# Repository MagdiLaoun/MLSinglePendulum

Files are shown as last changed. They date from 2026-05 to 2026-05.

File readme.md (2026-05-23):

# Readme
This repository contains all the files needed to build a simple pendulum.
- **Inverted pendulum (English).pdf**: theory of pendulum kinematics and balance control, English version
- **Inverted pendulum (French).pdf**: theory of pendulum kinematics and balance control, French version
- **ComponentList.md**: Bill of material of the machine
- **Single Pendulum STL**: Folder containing all the 3D-print parts in stl format
- **Single Pendulum Circuit**: Folder containing the pcb (schematic + footprint) drawn on Kicad, this circuit allows to connect electrically all the parts together (motor, controller, etc.)
- **Single Pendulum C++**: Folder containing the source code of the controller, written in C++, in VSCode PlatformIO
- **Single Pendulum SwiftUI**: Folder containing the source code of the program on the computer to set-up the system, to set the parameters and to launch the machine, written in SwiftUI, for MacOS computer

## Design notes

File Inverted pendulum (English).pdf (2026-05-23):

# Inverted pendulum

Magdi Laoun, 17.12.2025

## 1 Abstract

An inverted pendulum is a pendulum that is held in equilibrium at the top in an unstable position. It can pivot at its base around an axis that is attached to a carriage capable of moving horizontally. With the help of a motor, the carriage moves to try to maintain this equilibrium position.

An angular sensor mounted on the carriage axis measures the pendulum’s angle relative to the vertical in real time, and this data is processed by a microcontroller, which controls the motor to maintain balance.

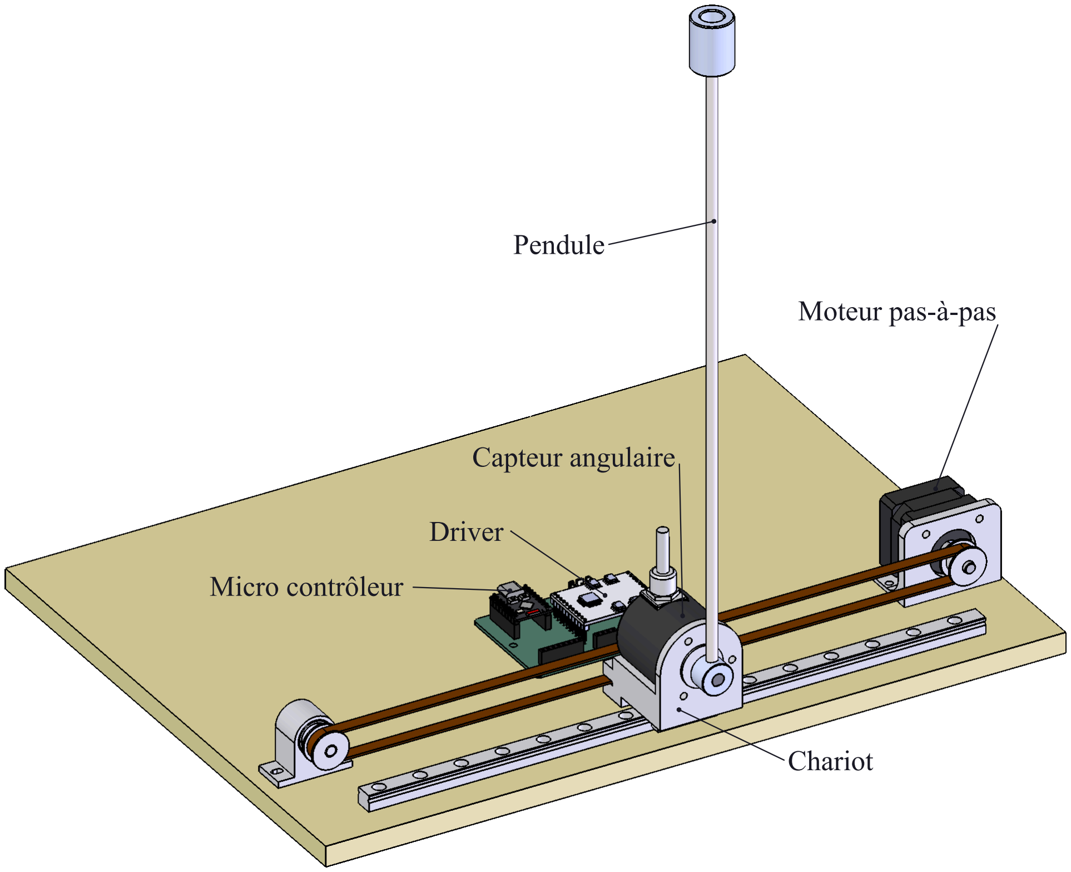
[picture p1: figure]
Pendule; Moteur pas-à-pas; Capteur angulaire; Chariot; Micro contrôleur; Driver
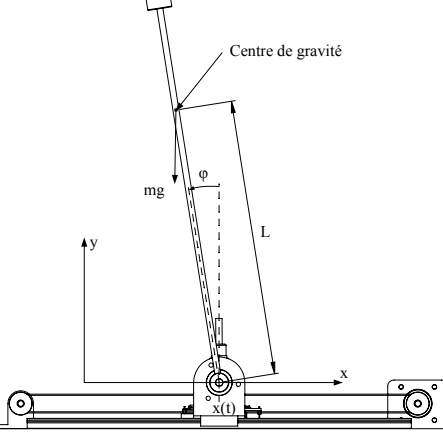
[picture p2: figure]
Centre de gravité

Figure 1: Geometry of the pendulum

## 2 Objectives

- Determine the movement of the carriage (and thus the motor) based on the pendulum’s angle and position, so as to keep it vertical and centered on the rail.
- Determine the motor control coefficients needed to keep this pendulum in balance.

## 3 Data and hypotheses

- The motor has 200 steps per revolution and 16 microsteps per step, which amounts to 3,200 microsteps per revolution. The motor is a stepper motor. Consequently, the motor’s position, speed, and acceleration do not depend on the load but solely on the electrical command provided by the controller.
- The motor pulley has a circumference of 40 mm. From this, we can deduce that the carriage moves 10 mm in 800 steps per revolution.
- The angle sensor mounted on the carriage, which measures the angular position of the pendulum, has a resolution of 10,000 counts per revolution.
- The total mass, moment of inertia, and center of gravity of the pendulum are known and provided by 3D modeling software.
- The pendulum’s axis, at its base, is fixed by the carriage, with no play and no friction.
- The carriage moves only horizontally along the x-axis.
- All units used in the formulas and calculations are those of the International System of Units. For practical and readability reasons, different units may be used to denote a given value or result, such as millimeters for length, or grams
- 1 -

## 4 Settings and terminology

Paramètre | Signification
m | segment mass i
l | segment length i
p | Angular position of the pendulum
φ̇ | Angular velocity of the pendulum
φ̈ | Angular acceleration of the pendulum
x | Carriage position
ẋ | Carriage velocity
ẍ | Carriage acceleration

## 5 Kinematics

### 5.1 Lagrange’s equations

We will solve the equations of motion using Lagrange’s equations (energy balance).

L︀ = T − V

Where T is the kinetic energy of the system and V is its potential energy.

Since we are dealing with a stepper motor in which the rotor’s acceleration is imposed by the motor and not caused by the load, we will assume that the mass of the carriage is zero. The kinetic energy of the system is therefore limited solely to the energy of the pendulum itself.

T =

1
2

mv

2
p

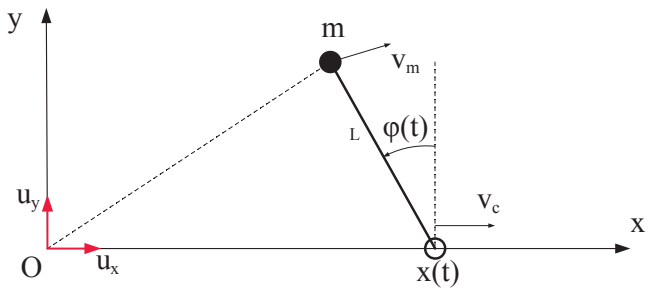
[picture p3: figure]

Figure 2: Geometry of the pendulum

Position of the pendulum

xp = x − lsin φ

yp = l cos φ

Velocity of the pendulum

ẋp = ẋ− lφ̇cos φ

ẏp = −lφ̇sin φ

→ v

2
p = ẋ

2
p + ẏ

2
p = ẋ

2 − 2xl̇ φ̇cos φ + l

2φ̇

2

cos² φ + l

2φ̇

2

sin² φ = ẋ

2 − 2xl̇ φ̇cos φ + l

2φ̇

2

Kinetic energy

Kinetic energy is therefore equal to: T =

1
2m(ẋ

2 − 2xl̇ φ̇cos φ + l

2φ̇

2
)
- 2 -

Potential energy

As for potential energy, it is equal to: V = mgl cos φ

Lagrangien

The Lagrangian is therefore written as: ℒ︀ =

1
2m(ẋ

2 − 2xl̇ φ̇cos φ + l

2φ̇

2
) − mgl cos φ

### 5.2 Euler-Lagrange equations

Let’s define the following vector:
q = (
x
φ

)

The general form of the Euler-Lagrange equations is given by:

d
dt

(
∂ℒ︀
∂q ̇

) −
∂ℒ︀
∂q = u

where u is the external generalized forces.

Since we are dealing with a stepper motor whose linear motion of the carriage is fully determined, we are not interested in the linear component along the x-axis; therefore, we will solve the Euler-Lagrange equation for the angular component only, and thus u = 0:

∂ℒ︀
∂φ̇ = −mlẋcos φ + mlφ̇

d
dt

(
∂ℒ︀
∂φ̇

) = −mlẍcos φ + mlxφ̇ ̇sin φ + ml 2φ̈

∂ℒ︀
∂φ = mlxφ̇ ̇sin φ + mglsin φ

The Euler-Lagrange equation is therefore written as:

d
dt

(
∂ℒ︀
∂q ̇

) −
∂ℒ︀
∂q = −mlẍcos φ + mlxφ̇ ̇sin φ + ml

2φ̈− mlxφ̇ ̇sin φ − mglsin φ = 0

After simplifying, we get:

−ẍcos φ + lφ̈− g sin φ = 0

This gives us the following differential equation:

φ̈=

g
l

sin φ +

1
l

ẍcos φ

### 5.3 Linearization around the equilibrium point

Around the equilibrium point φ ≈ 0, we can make the following approximations:

sin φ ≈ φ et cos φ ≈ 1

This simplifies the equation above:

φ̈=

g
l

φ +

1
l

ẍ

## 6 Matrix formulation

Let’s define the following state variable: X =
(

φ
φ̇
x
ẋ)

The state variable is a variable that describes the pendulum’s state at any given time t. The pendulum’s state at time t is determined by the variables φ, φ̇, x, and d

so that the equation of state can be expressed as follows:

Ẋ = AX + Bẍ

- 3 -where A and B are matrices 4✗4 to be determined. The equation can be written as follows:

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
+ Bẍ

where A and B are matrices. The equation of motion allows us to determine these matrices:

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
and B =
(

0
1
l
0
1)

This state equation is a linear quadratic differential equation, hence the name LQR, which stands for Linear Quadratic Regulation.

We will return to this equation of state later.

## 7 LQR Control

### 7.1 Introduction

Everything that has been done so far is preparatory work that will be used to achieve our goal here, namely, a control rule for the carriage acceleration based on the state variable that keeps the system in equilibrium.

ẍ= −KX

where

x is the acceleration that must be applied to the carriage to keep the pendulum in equilibrium ̈

X =
(

φ
φ̇
x
ẋ)

is the system’s state variable

K = (kpa kda kpx kdx) are the control coefficients, and that is precisely what we are looking for.

The whole challenge lies in finding these four coefficients, which are key to successful control. We will examine this aspect in the next section.

### 7.2 Riccati function

Let:

εp1

and εp2
: the quadratic errors of the angles of the pendulum’s two segments relative to its equilibrium position

The control parameter K is optimal if:

- These two quadratic errors are minimized over a certain period
- The motor’s effort required to achieve this is minimized

The Ricatti function, named after its inventor, allows us to calculate this quadratic deviation as well as the motor’s effort using an integral over a certain period. The control parameter K will be optimal when this result is minimized. The Ricatti function is as follows:

J = ∫

∞

0

(XTQX + Rẍ

2
)dx

where:

- Q is a weighting matrix used to assign weights to any of the state variables φ, φ̇, x, or ẋ
- R is a weighting coefficient used to assign a weight to the control cost
- 4 -

For given weights, the control is optimal if this function is minimized

The form of these two weights is as follows:

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
qẋ)

and

R = r

A good place to start is to ask:

- qφ = 1000
- qφ̇ = 1000
- qx = 10
- qẋ = 10
- r = 1

### 7.3 Calculation of LQR control

From this, and according to Ricatti, there exists a matrix P 4✗4 such that

AT P + PA − PBR⁻¹BT P + Q = 0

Determining P by solving this matrix equation would, in theory, allow us to determine the coefficients K using the other Ricatti equation

K = R⁻¹BT P

In practice, and in most cases, it is not possible to determine this matrix P analytically, given the nonlinear and differential nature of the relationships between the various parameters and variables.

However, it is possible to determine this matrix P numerically using computational tools such as MATLAB, which provides a specific tool for solving this problem, or by using a computer program that will be described below.

### 7.3.1 Differential equation, Riccati method

A Riccati differential equation has the following form:

ẏ= q0

(x) + q1

(x)y + q2

(x)y

2

where q0

, q1

et q2
are three known functions.

The Riccati differential equation also applies to matrices. In our case, we have

Ṗ = AT P + PA − PBR⁻¹BT P + Q

with Ṗ → 0 when t → ∞

To determine P, simply apply Euler’s method, taking as the initial condition, for example, P0 = I (the identity matrix), and iteratively solve the following equation:

Pk+1 = Pk + dtṖ
k
Until ‖Ṗ‖ → 0 (matrix norm)

In practice, all you need to do is choose dt sufficiently small—for example, dt = 0.001—and you will see that the solution converges fairly quickly, after about 1000 iterations.

- 5 -

Note

Note that if the number of iterations is too high, rounding errors will cause the solution to diverge again.

### 7.4 Numerical example

Using code written in Swift for macOS, we calculated the various matrices A, B, and Q and performed the different operations needed to determine the matrix A and the coefficients K.

- length: l = 300 mm
- gravity: g = 9.81 m/s

2

These data (in SI units: kg, m, etc.) allow us to determine matrices A and B

A =
(

0
32.7
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
3.33
0
0 )

Regarding the weighting matrix, we will prioritize angle and position over damping rate, using an effort cost of r = 1 as the baseline

Q =
(

1000
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
1000
0

0
0
0
1)

Using a program code that allows us to manipulate matrices (addition, subtraction, multiplication, transposition, etc.) and a loop that calculates, iteratively and using Euler’s method, the equation we saw in the 7.3.1 section, we obtain the following matrix P (rounded to the nearest integer):

P =
(

531
85
−412
−201

85
16
−78
−40

−412
−78
677
228

−201
−40
228
113 )

And finally, this allows us to determine the following LQR control coefficients:

K =
(

80.0
12.8
−31.6
−20.8)

which allows us to determine the acceleration that must be applied to the motor to keep the pendulum in equilibrium (SI units: angle: rad, acceleration: m
s

2 ).

ẍ= −KX = −80.0 ⋅ φ − 12.8 ⋅ φ̇+ 31.6 ⋅ x + 20.8 ⋅ ẋ

### 7.5 Practical test

With the values above, the device works perfectly. However, the device performs even better with the following coefficients, which were determined through trial and error:

- 6 -ẍ= −KX = −220.0 ⋅ φ − 22.0 ⋅ φ̇+ 224.0 ⋅ x + 62.0 ⋅ ẋ

This difference is likely due to the choice of values for the weighting matrix. In any case, the machine works perfectly whether you use the theoretical values or values determined by trial and error.

### 7.6 Program Convergence

We conducted several convergence tests on the Ricatti differential equation by varying the number of steps and the step size in the Euler method solution.

Nombre incréments | dt
50 | 0.04
100 | 0.02
1000 | 0.002

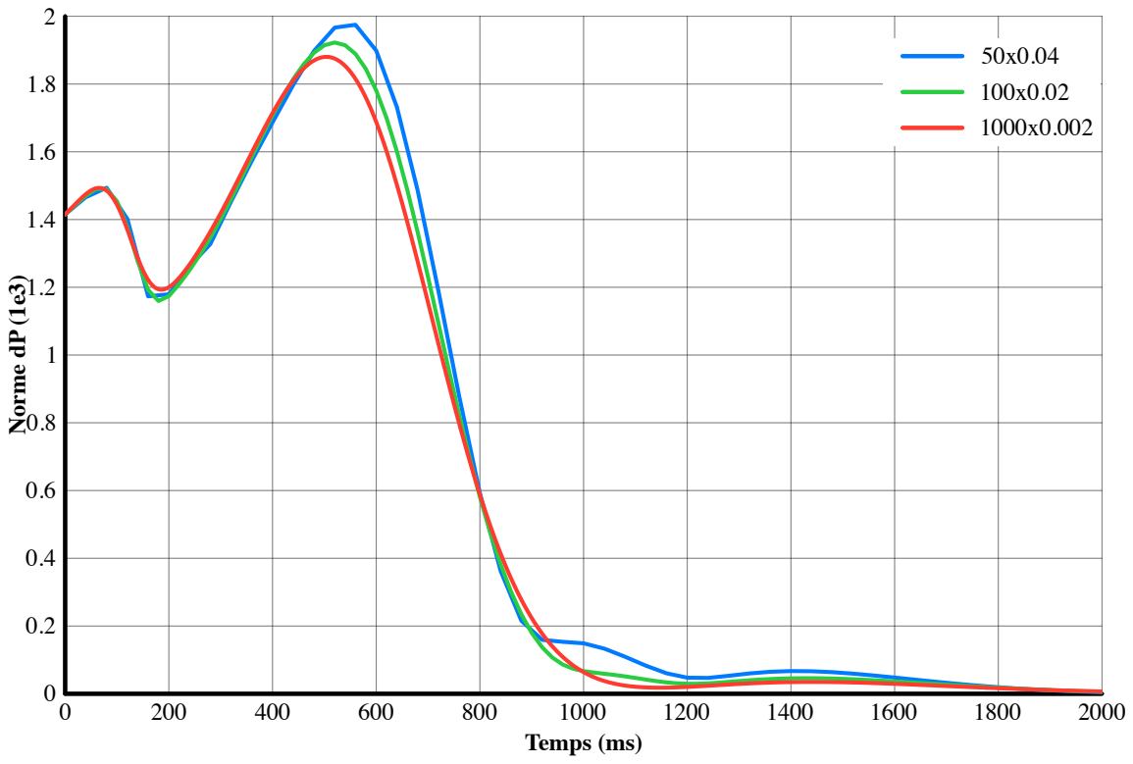
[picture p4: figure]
Temps (ms); Norme dP (1e3)

Figure 3: Norm of Ṗ

What this graph shows is the norm of the matrix Ṗ = AT P + PA − PBR⁻¹BT P + Q during the iterations.

We can see that convergence is achieved relatively quickly, even with a large step size of dt = 0.04

## 8 Swing up

The “swing-up” is the process of raising the pendulum from its resting position at the bottom.

There are several methods for performing the swing-up.

A simple method involves moving the carriage back and forth, as one would on a swing, synchronized with the angle of the pendulum, so that with each movement of the carriage, the pendulum increases its speed enough to rise to the vertical position. There are two constraints:

- 7 -

- The carriage’s movement must be synchronized with the pendulum’s position: each time the pendulum passes through the bottom position, a movement is performed in the opposite direction of its velocity.
- When the carriage reaches a certain threshold angle (for example, 160°), it switches to top-position balance control mode. But be careful: the pendulum’s speed must not be too high during the switch, otherwise balance cannot be maintained and the pendulum will continue its swing to the other side.

Another method involves controlling the carriage based on the balance of the pendulum’s potential and kinetic energy. It is this method that we will examine below.

### 8.1 Energy balance method

The idea behind this method is to impart kinetic energy to the pendulum through the movement of the carriage; this energy will be converted into potential energy as the pendulum rises higher and higher, and the amount of energy imparted will depend on the position and velocity of the pendulum. Thus, the acceleration of the carriage is controlled by the pendulum’s energy balance, so that the pendulum reaches the top as quickly as possible. Let Ep

be the potential energy and Ec the kinetic energy of the pendulum

… To be continued….

## 9 Conclusions

From a kinematic perspective, determining the motion of the pendulum involves the Euler-Lagrange equations. This may seem complex at first glance, but it is ultimately manageable.

Furthermore, it is absolutely essential to clearly define the geometric data and, above all, the direction of the coordinates. Otherwise, a small sign error or a minor oversight can compromise the entire rest of the derivation.

The second part, which concerns the determination of the LQR control coefficients, is somewhat more complex. This derivation involves matrix operations as well as numerical computation to determine these control coefficients.

I would also like to highlight the achievements of the mathematician Riccati, who lived in the 17th century and did not have a computer to verify the accuracy of his formulas through practical testing.

Ultimately, we see that even for a problem as seemingly complex as the equilibrium of an inverted pendulum, a solution exists: we have been able to find a method to reliably determine the coefficients of the LQR control.

- 8 -

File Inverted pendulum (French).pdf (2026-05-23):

## Pendule inversé

Magdi Laoun, 17.12.2025

### 1 Introduction

Le pendule inversé est un pendule qui est maintenu en équilibre en haut dans une position instable. Il peut pivoter à sa base sur un axe qui est fixé à un chariot pouvant se déplacer horizontalement. A l’aide d’un moteur, le chariot va se déplacer pour tenter de maintenir cette position d’équilibre.

Dans l’axe du chariot, un capteur angulaire mesure en temps réel l’angle du pendule par rapport à la verticale et cette information est traitée par un microcontrôleur qui se charge de piloter le moteur pour maintenir l’équilibre.

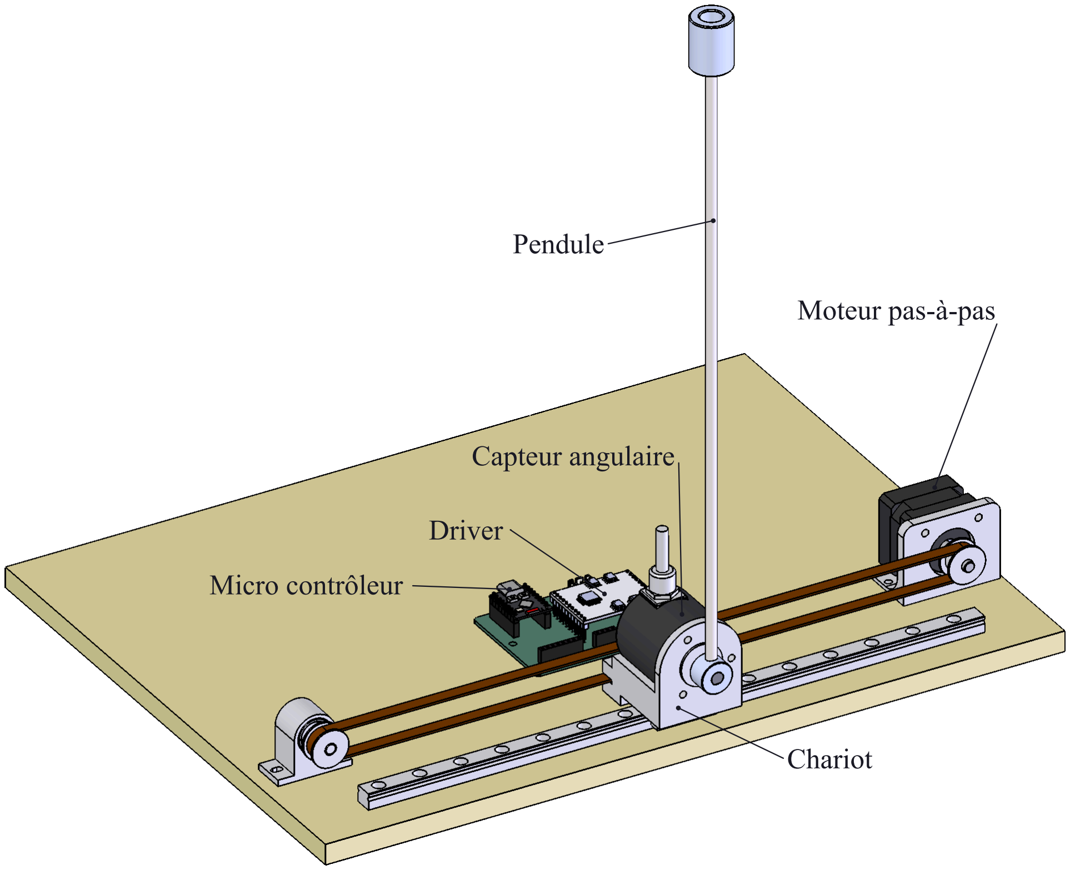
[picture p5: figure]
Pendule; Moteur pas-à-pas; Capteur angulaire; Chariot; Micro contrôleur; Driver
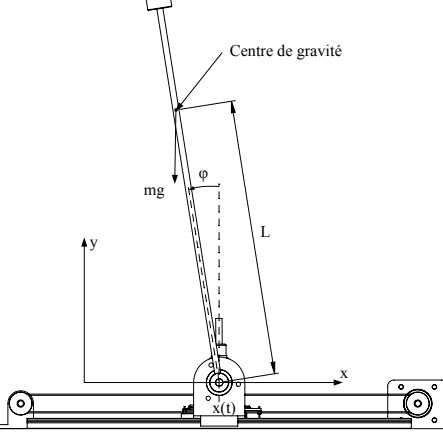
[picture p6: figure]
Centre de gravité

Fig. 1. – Géométrie du pendule

### 2 Objectifs

- Connaître le mouvement du chariot (et donc du moteur) en fonction de l’inclinaison du pendule et de sa position, de manière à le garder vertical et au centre du rail.
- Déterminer les coefficients de régulation du moteur pour garder ce pendule en équilibre.

### 3 Données et hypothèses

- Le moteur a 200 pas/tour et 16 micropas/pas. Ce qui donne 3200 micropas/tour. La motorisation est un moteur pas-à-pas. Par conséquent, la position, la vitesse et l’accélération du moteur ne dépendent pas de la charge mais uniquement de la consigne électrique fournie par la commande.
- La poulie du moteur a une circonférence de 40 mm. On en déduit qu’un déplacement de 10 mm du chariot se fait par 800 pas par tour.
- Le capteur d’angle fixé sur le chariot mesurant la position angulaire du pendule a une résolution de 10000 points par tour.
- La masse totale, l’inertie et le centre de gravité du pendule sont connus et donnés par un logiciel de dessin 3D.
- L’axe du pendule, à sa base, est contraint par le chariot, sans jeu et sans frottement.
- Le chariot se déplace uniquement horizontalement selon l’axe x.
- Toutes les unités utilisées pour les formules et calculs sont celles du Système International. Pour des raisons pratiques et de lisibilité on pourra utiliser des unités différentes pour désigner une valeur de donnée ou de résultat comme par exemple le mm pour une longueur, ou les grammes
- 1 -

### 4 Paramètres et nomenclature

Paramètre | Signification
m | masse du segment i
l | Longueur du segment i
p | Position angulaire du pendule
φ̇ | Vitesse angulaire du pendule
φ̈ | Accélération angulaire du pendule
x | Position du chariot
ẋ | Vitesse du chariot
ẍ | Accélération du chariot

### 5 Cinématique

### 5.1 Equation de Lagrange

On va résoudre les équations de mouvement par la formulation des équations de Lagrange (bilan des énergies).

L︀ = T − V

Où T est l’énergie cinétique de l’ensemble et V son énergie potentielle.

Vu qu’on a affaire à un moteur pas-à-pas dont l’accélération du rotor est donnée et non subie par la charge, on va considérer que la masse du chariot est nulle. L’énergie cinétique de l’ensemble se résume donc uniquement à l’énergie du pendule en lui-même.

T =

1
2

mv

2
p

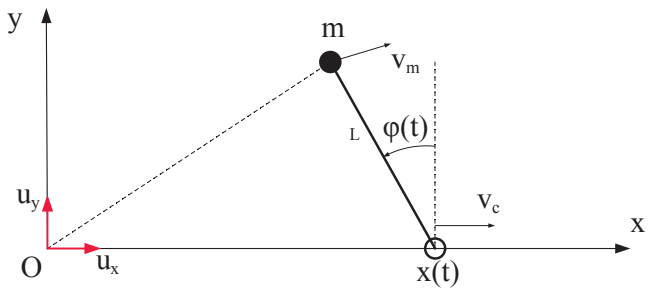
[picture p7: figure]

Fig. 2. – Géométrie du pendule

Position du pendule

xp = x − lsin φ

yp = l cos φ

Vitesse du pendule

ẋp = ẋ− lφ̇cos φ

ẏp = −lφ̇sin φ

→ v

2
p = ẋ

2
p + ẏ

2
p = ẋ

2 − 2xl̇ φ̇cos φ + l

2φ̇

2

cos² φ + l

2φ̇

2

sin² φ = ẋ

2 − 2xl̇ φ̇cos φ + l

2φ̇

2

Energie cinétique
L’énergie cinétique est donc égale à: T =

1
2m(ẋ

2 − 2xl̇ φ̇cos φ + l

2φ̇

2
)
- 2 -

Energie potentielle
Quant à l’énergie potentielle, elle est égale à: V = mgl cos φ

Lagrangien
Le Lagrangien s’écrit donc: ℒ︀ =

1
2m(ẋ

2 − 2xl̇ φ̇cos φ + l

2φ̇

2
) − mgl cos φ

### 5.2 Equations d’Euler-Lagrange

Définissons le vecteur suivant:
q = (
x
φ

)

La forme généralisée des équations d’Euler-Lagrange est donnée par :

d
dt

(
∂ℒ︀
∂q ̇

) −
∂ℒ︀
∂q = u

où u est les forces généralisées externes.

Étant donné que nous avons affaire à un moteur pas-à-pas dont le mouvement linéaire du chariot est entièrement déterminé, la partie linéaire en x ne nous intéresse pas, nous allons résoudre l’équation d’Euler-Lagrange pour la partie angulaire uniquement, et donc u = 0:

∂ℒ︀
∂φ̇ = −mlẋcos φ + mlφ̇

d
dt

(
∂ℒ︀
∂φ̇

) = −mlẍcos φ + mlxφ̇ ̇sin φ + ml 2φ̈

∂ℒ︀
∂φ = mlxφ̇ ̇sin φ + mglsin φ

L’équation d’Euler-Lagrange s’écrit donc:

d
dt

(
∂ℒ︀
∂q ̇

) −
∂ℒ︀
∂q = −mlẍcos φ + mlxφ̇ ̇sin φ + ml

2φ̈− mlxφ̇ ̇sin φ − mglsin φ = 0

Après simplification, on obtient:

−ẍcos φ + lφ̈− g sin φ = 0

Ce qui nous donne l’équation différentielle suivante:

φ̈=

g
l

sin φ +

1
l

ẍcos φ

### 5.3 linéarisation autour de l’équilibre

Autour de l’équilibre φ ≈ 0, nous pouvons faire les approximations suivantes:

sin φ ≈ φ et cos φ ≈ 1

Ce qui simplifie l’équation ci-dessus:

φ̈=

g
l

φ +

1
l

ẍ

### 6 Formulation matricielle

Définissons la variable d’état suivante: X =
(

φ
φ̇
x
ẋ)

La variable d’état est une variable qui décrit une situation du pendule à tout instant t. L’état du pendule à l’instant t est en effet déterminé par les variables φ, φ̇, x et d

de tel sorte que l’on peut formuler l’équation d’état de cette manière:

Ẋ = AX + Bẍ

- 3 -où A et B sont des matrices 4✗4 à déterminer. L’équation peut s’écrire ainsi:

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
+ Bẍ

où A et B sont des matrices. L’équation de mouvement nous permet de déterminer ces matrices:

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
et B =
(

0
1
l
0
1)

Cette équation d’état est une fonction différentielle linéaire quadratique, d’où l’appellation LQR, qui est l’acronyme en anglais de Linear Quadratic Regulation.

Nous reviendrons plus loin sur cette équation d’état.

### 7 Commande LQR

### 7.1 Introduction

Tout ce qui a été fait précédemment est un travail qui va servir à ce qu’on recherche ici, à savoir une règle de commande de l’accélération du chariot en fonction de la variable d’état qui permet de maintenir le système en équilibre.

ẍ= −KX

où

x est l’accélération à appliquer au chariot pour maintenir le pendule en équilibre ̈

X =
(

φ
φ̇
x
ẋ)

est la variable d’état du système

K = (kpa kda kpx kdx) sont les coefficients de régulation, et c’est précisément ce que l’on recherche.

Tout le problème consiste à trouver ces 4 coefficients, synonyme d’une régulation réussie. Nous regarderons cet aspect au paragraphe suivant.

### 7.2 Fonction de Riccati

Soit:

εp1

et εp2

: les écarts quadratiques des angles des 2 segments du pendule par rapport à sa position d’équilibre

Le paramètre de régulation K est optimum si:

- Ces deux écarts quadratiques sont minimum durant une certaine période
- L’effort du moteur pour y parvenir est minimum

La fonction de Ricatti, du nom de son inventeur, permet de calculer au moyen d’une intégrale pendant une certaine période cet écart quadratique ainsi que l’effort du moteur. Le paramètre de régulation K sera optimum lorsque ce résultat sera minimum. La fonction de Ricatti est la suivante:

J = ∫

∞

0

(XTQX + Rẍ

2
)dx

où:

- Q est une matrice de pondération permettant de donner du poids à l’une ou l’autre des variables d’état φ, φ̇, x ou ẋ
- 4 -

- R un coefficient de pondération permettant de donner du poids au coût de la régulation

Pour des pondérations données, la régulation est optimale si cette fonction est minimale

La forme de ces 2 pondérations est la suivante:

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
qẋ)

et

R = r

Une bonne base de départ est de poser:

- qφ = 1000
- qφ̇ = 1000
- qx = 10
- qẋ = 10
- r = 1

### 7.3 Calcul de la régulation LQR

À partir de là, et selon Ricatti, il existe une matrice P 4✗4 tel que

AT P + PA − PBR⁻¹BT P + Q = 0

La détermination de P par la résolution de cette équation de matrices nous permettrait, en théorie, de déterminer les coefficients K à l’aide de l’autre équation de Ricatti

K = R⁻¹BT P

Dans la pratique, et dans la plupart des cas, il n’est pas possible de déterminer de manière analytique cette matrice P, étant donné le caractère non linéaire et différentiel qui lie les différents paramètres et variables.

Toutefois, il est possible de connaître de manière numérique cette matrice P au moyen d’outils de calcul comme Matlab qui met à disposition un outil spécifique à la résolution de ce problème, ou alors au moyen d’un programme informatique que l’on va expliciter ci-dessous.

### 7.3.1 Résolution différentielle, méthode de Riccati

Une équation différentielle de Riccati est de la forme suivante:

ẏ= q0

(x) + q1

(x)y + q2

(x)y

2

où q0

, q1

et q2

sont 3 fonctions connues.

L’équation différentielle de Riccati est aussi applicable pour des matrices. Dans notre cas, nous avons

Ṗ = AT P + PA − PBR⁻¹BT P + Q

avec Ṗ → 0 lorsque t → ∞

Pour déterminer P, il suffit d’appliquer la méthode d’Euler en prenant comme condition initiale par exemple P0 = I (Matrice unité)et de calculer de manière itérative l’équation suivante:

Pk+1 = Pk + dtṖ
k
Jusqu’à ce que ‖Ṗ‖ → 0 (norme matricielle)
- 5 -

Concrètement, il suffit de prendre dt suffisamment petit, par exemple dt = 0.001, et on constate que la solution converge assez rapidement, à partir d’un nombre d’itération d’environ 1000.

Remarque
Attention, si le nombre d’itérations est trop grand, les erreurs d’arrondis vont faire en sorte que la solution va à nouveau diverger.

### 7.4 Exemple numérique

À l’aide d’un code écrit en Swift pour MacOS, nous avons calculé les diverses matrices A, B et Q et exécuté les différentes opérations permettant de déterminer la matrice A et les coefficients K.

- longueur: l = 300 mm
- gravité: g = 9.81 m/s

2

Ces données (en unité SI: Kg, m, etc.) nous permettent de déterminer les matrices A et B

A =
(

0
32.7
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
3.33
0
0 )

Concernant la matrice de pondération, on va privilégier l’angle et la position plutôt que la vitesse d’amortissement, avec comme base de coût d’effort r = 1

Q =
(

1000
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
1000
0

0
0
0
1)

Au moyen d’un code-programme permettant de manipuler des matrices (additions soustractions, multiplications, transpositions, etc.) et d’une boucle permettant de calculer de manière itérative et par la méthode d’Euler l’équation que nous avons vue au point 7.3.1, on obtient la matrice P suivante (arrondie sans décimale):

P =
(

531
85
−412
−201

85
16
−78
−40

−412
−78
677
228

−201
−40
228
113 )

Et finalement, cela nous permet de déterminer les coefficients de régulation LQR suivants:

K =
(

80.0
12.8
−31.6
−20.8)

qui nous permet d’obtenir l’accélération à appliquer au moteur pour maintenir le pendule en équilibre (unités SI: angle: rad, accélération: m/s

2
).

ẍ= −KX = −80.0 ⋅ φ − 12.8 ⋅ φ̇+ 31.6 ⋅ x + 20.8 ⋅ ẋ

- 6 -

### 7.5 Test pratique

Avec les valeurs ci-dessus, l’appareil construit fonctionne parfaitement. Cependant, l’appareil fonctionne encore mieux avec les coefficients suivants trouvés par tâtonnement:

ẍ= −KX = −220.0 ⋅ φ − 22.0 ⋅ φ̇+ 224.0 ⋅ x + 62.0 ⋅ ẋ

Cette différence provient probablement du choix des valeurs de la matrice de pondération. Quoi qu’il en soit, le machine fonctionne parfaitement que l’on prenne les valeurs théoriques ou les valeurs par tâtonnement.

### 7.6 Convergence du programme

Nous avons effectué quelques tests de convergence de l’équation différentielle de Ricatti en modifiant le nombre d’incréments et la finesse d’incréments dans la résolution par la méthode d’Euler.

Nombre incréments | dt
50 | 0.04
100 | 0.02
1000 | 0.002

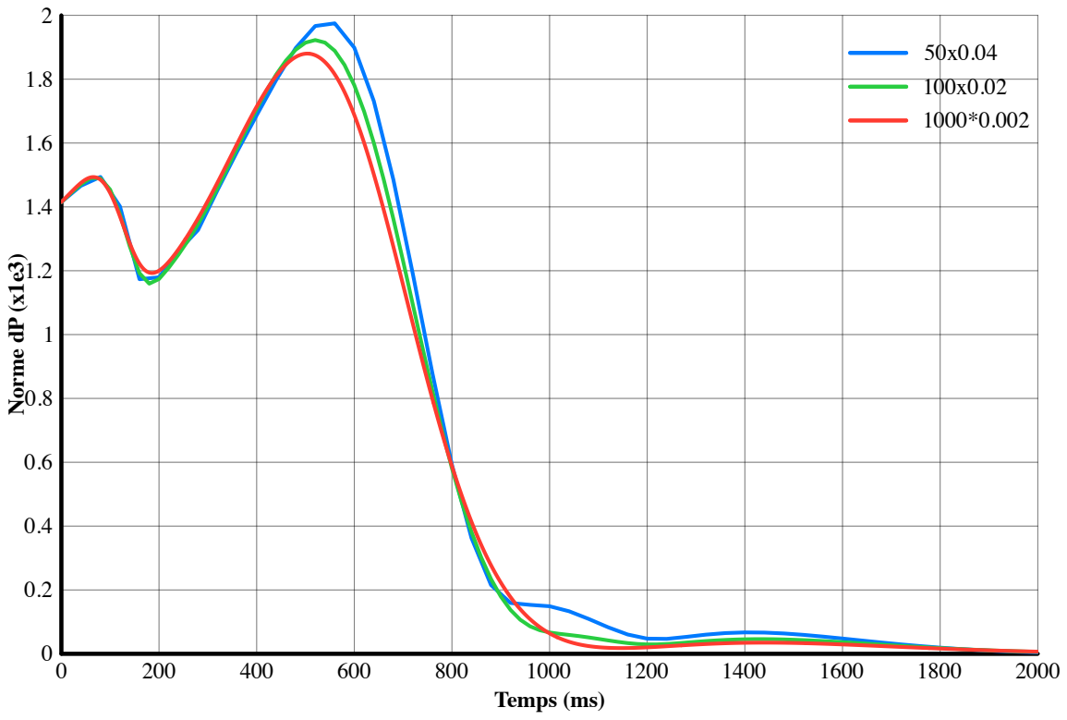
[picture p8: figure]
Temps (ms); Norme dP (x1e3)

Fig. 3. – Norme de Ṗ

Ce que l’on mesure, dans ce graphique, c’est la norme de la matrice Ṗ = AT P + PA − PBR⁻¹BT P + Q au cours des itérations.

On constate que la convergence est relativement vite atteinte, même avec un incrément grossier de dt = 0.04

- 7 -

### 8 Conclusions

D’un point de vue de la cinématique, la détermination du mouvement du pendule fait intervenir les équations d’Euler-Lagrange. Cela semble complexe au premier abord, mais finalement cela reste accessible.

D’autre part, il est absolument nécessaire de bien poser les données de la géométrie et surtout le sens des coordonnées. Autrement, une petite erreur de signe ou petite faute d’inattention peut contaminer tout le reste du développement.

La deuxième partie, celle qui concerne la détermination des coefficients de régulation LQR, est un peu plus complexe. Ce développement fait intervenir des manipulations de matrices ainsi que du calcul numérique pour pouvoir déterminer ces coefficients de régulation.

J’aimerais aussi souligner la performance du mathématicien Riccati, qui a vécu au 17ème siècle, et qui ne possédait pas d’ordinateur pour vérifier par la pratique l’exactitude de ses formules.

Au final, on constate que même pour un problème d’apparence complexe comme l’équilibre d’un pendule inversé, une solution existe, l’on a pu trouver une méthode pour déterminer de manière fiable les coefficients de la régulation LQR.

- 8 -

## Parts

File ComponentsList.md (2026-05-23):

| Quantity | Description | Supplier | Link |
| --- | --- | --- | ---|
| 1 | Incremental encoder 2500PR | AliExpress  | https://de.aliexpress.com/item/1005008882524645.html |
| 1 | Teethed belt GT2-6mm 2m | AliExpress  | https://de.aliexpress.com/item/10000401582873.html |
| 1 | Rail MGN12C 600 mm | AliExpress  | https://de.aliexpress.com/item/1000007480470.html |
| 1 | Microcontroller ESP32-C3 | AliExpress  | https://de.aliexpress.com/item/1005005967641936.html |
| 1 | Stepper NEMA17" 40 x 40 | AliExpress  | https://de.aliexpress.com/item/4000022185553.html |
| 2 | Ball bearing 625 5x16x5 | AliExpress  | https://de.aliexpress.com/item/1005008094013486.html |
| 1 | Driver Trinamic TMC5160-BOB | Farnell | https://ch.farnell.com/en-CH/trinamic-analog-devices/tmc5160-bob/breakout-board-stepper-motor-controller/dp/2846895 |
| 1 | PCB connect micro and driver | PCBWay | [See video No3 Youtube](https://www.youtube.com/watch?v=S2rUFUoVKJE) |
| 1 | Wooden base board 800x200x16 mm | Do-it | |
| 1 | threaded shaft M5 x 300 mm | Do-it | |
| 1 | Shaft 5 mm | Do-it | |
| Some | 3D-print-parts, support, etc. | | |
| Some | screws | | |

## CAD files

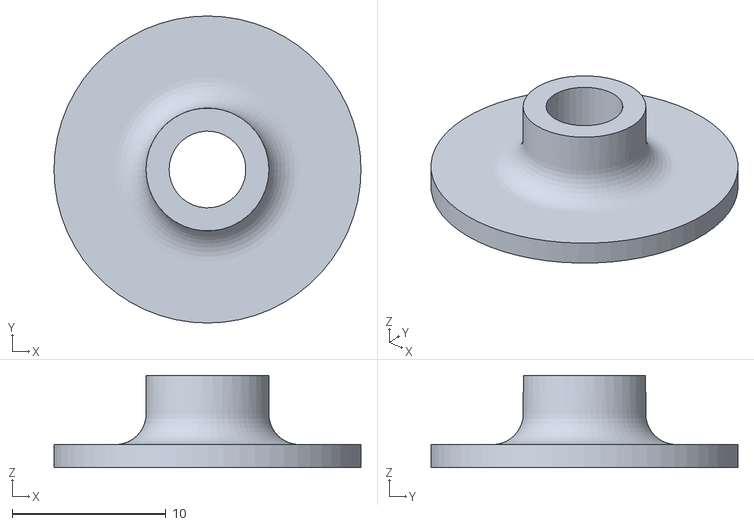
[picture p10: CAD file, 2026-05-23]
Single Pendulum STL/Plateau.STL
20.0 x 20.0 x 6.00

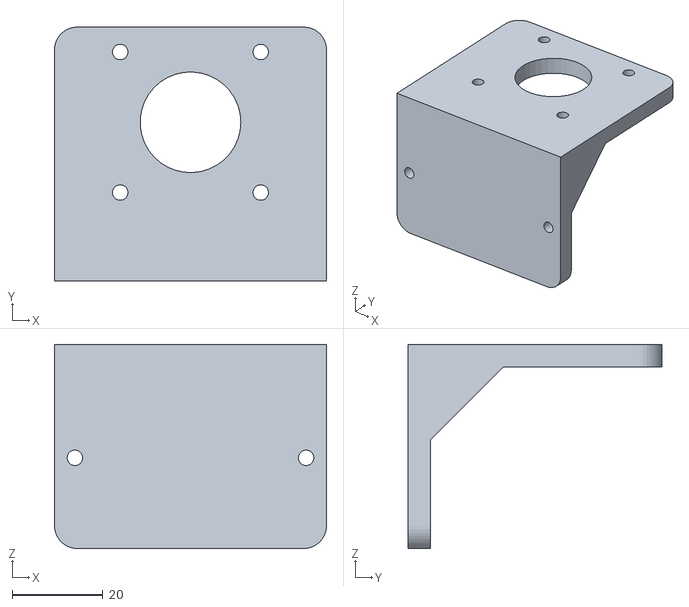
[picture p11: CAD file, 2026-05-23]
Single Pendulum STL/Motor flange.STL
60.0 x 56.0 x 45.0

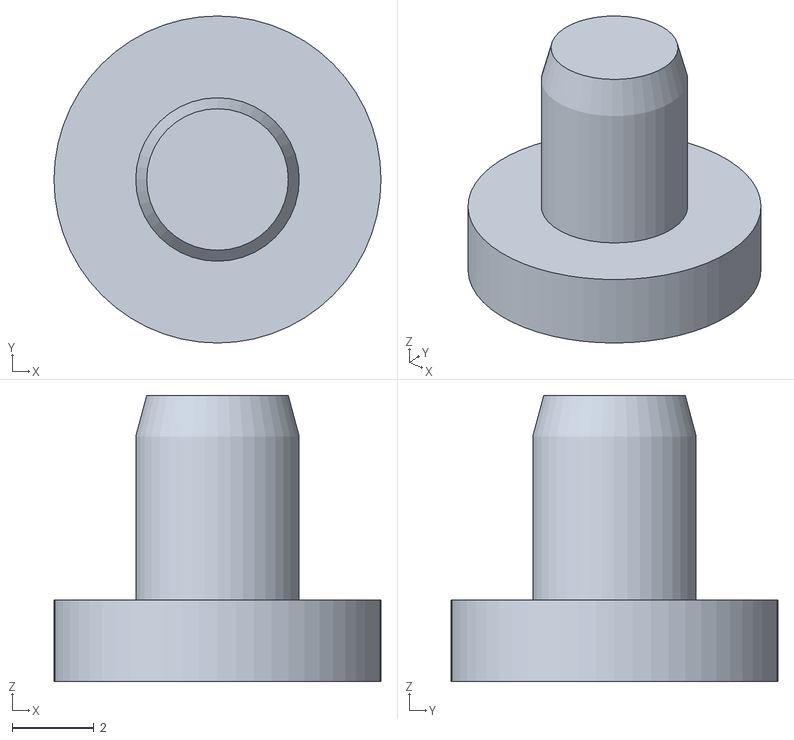
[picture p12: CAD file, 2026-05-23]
Single Pendulum STL/Embout_Axe.STL
8.00 x 8.00 x 7.00

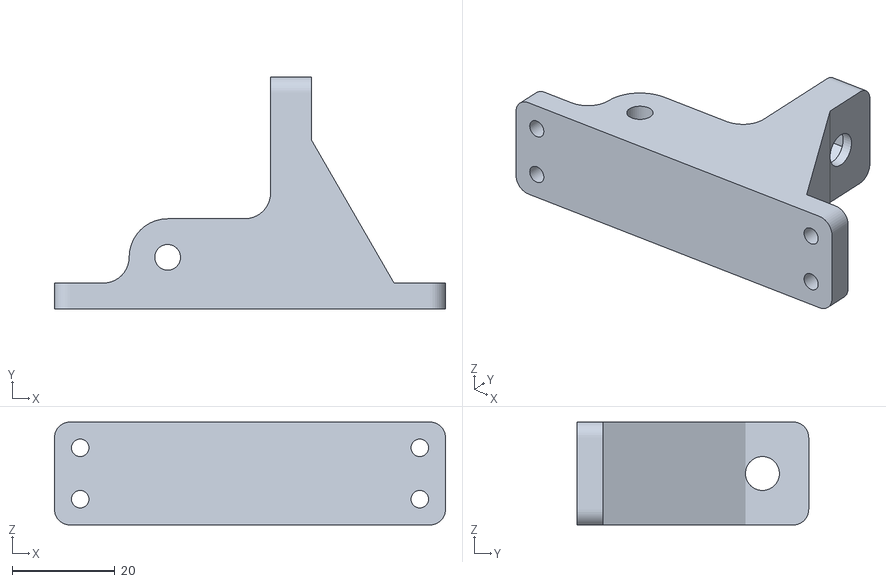
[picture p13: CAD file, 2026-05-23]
Single Pendulum STL/Support_Tendeur.STL
76.0 x 45.0 x 20.0

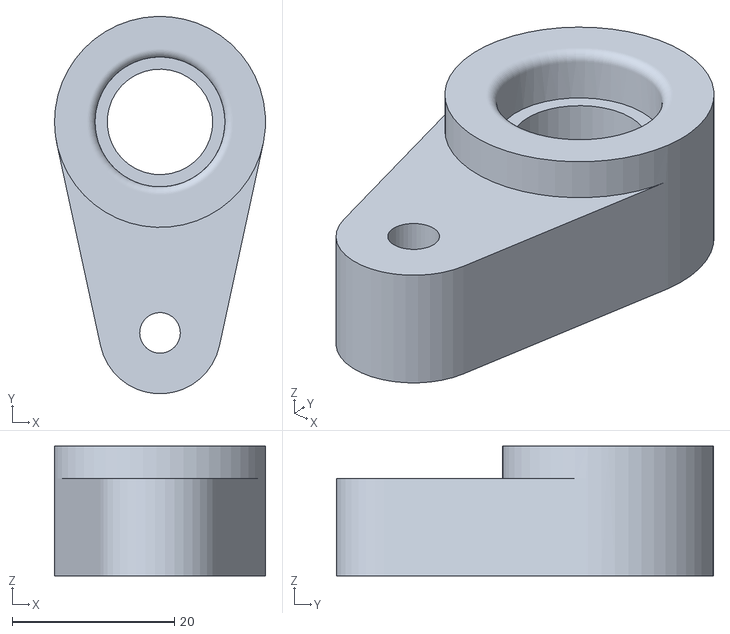
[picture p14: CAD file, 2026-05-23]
Single Pendulum STL/Tendeur.STL
26.0 x 46.5 x 16.0

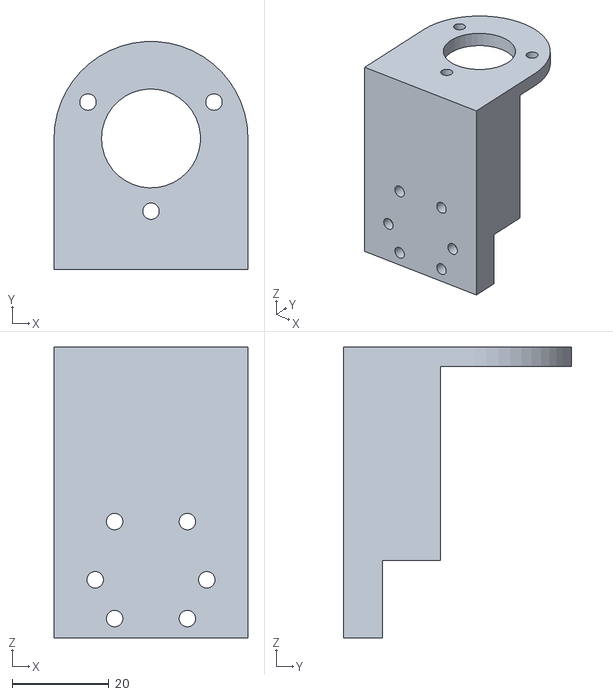
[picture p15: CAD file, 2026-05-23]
Single Pendulum STL/Support_Codeur5.STL
40.0 x 47.0 x 60.0

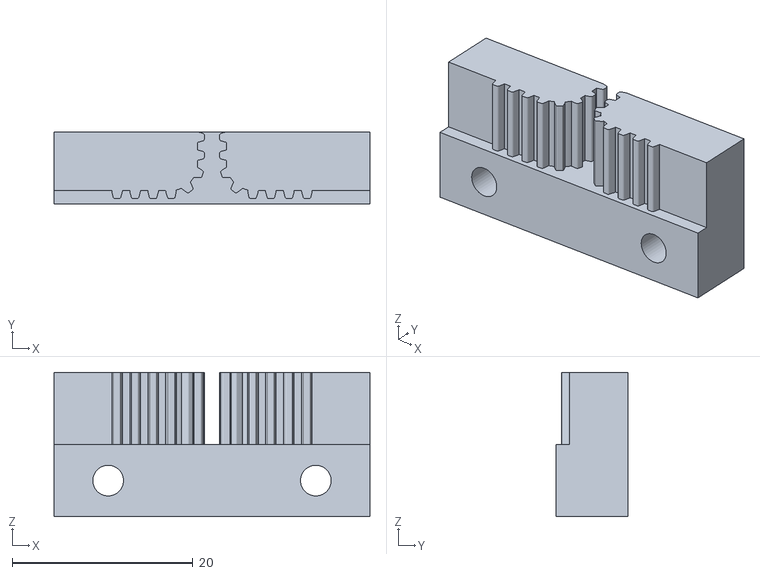
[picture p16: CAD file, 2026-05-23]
Single Pendulum STL/Fixation_Courroie.STL
35.0 x 8.00 x 16.0

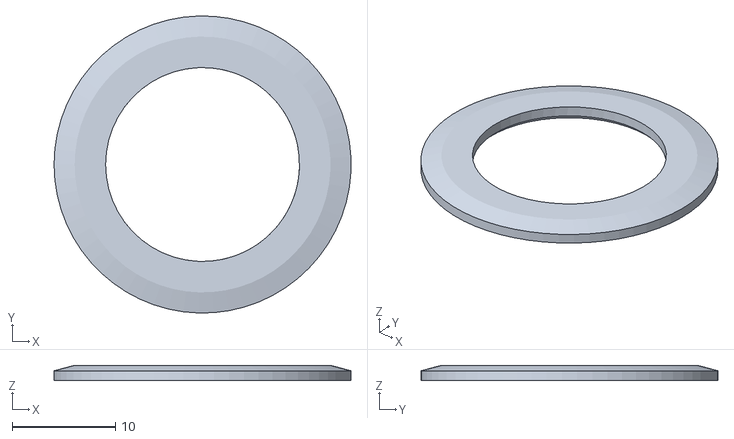
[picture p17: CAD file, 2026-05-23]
Single Pendulum STL/Flasque_Roue.STL
28.8 x 28.8 x 1.50

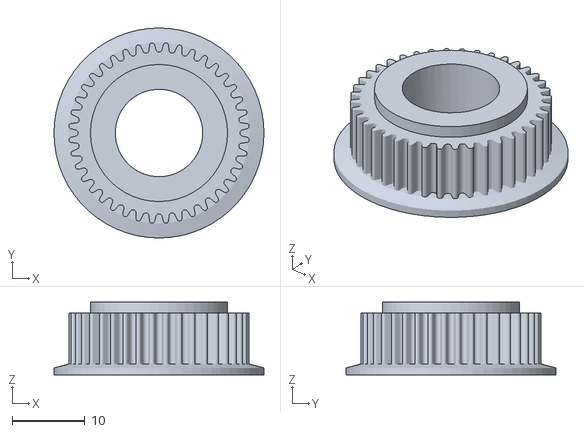
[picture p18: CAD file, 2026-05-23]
Single Pendulum STL/Roue_Dentée2.STL
28.8 x 28.8 x 10.0

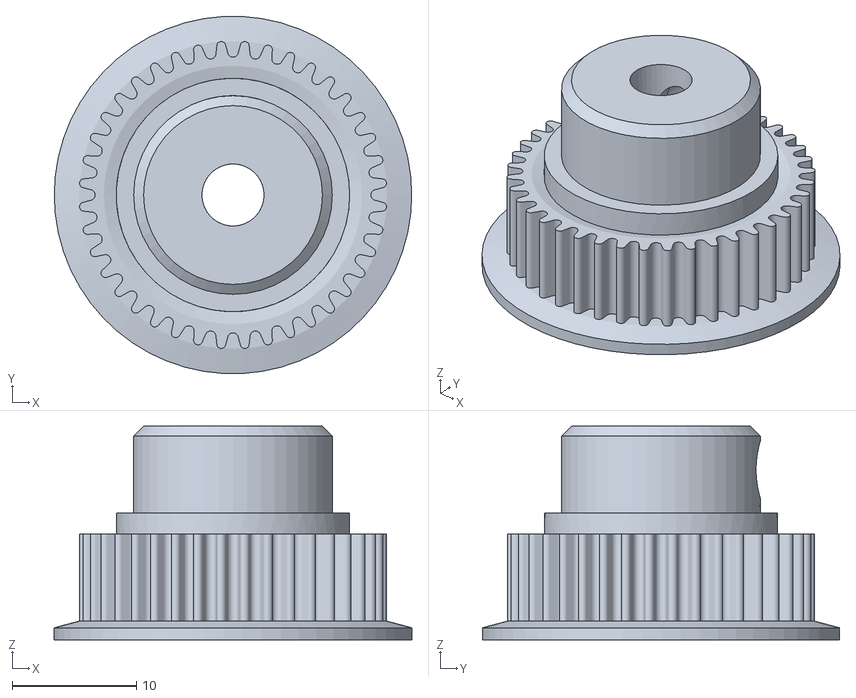
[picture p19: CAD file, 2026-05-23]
Single Pendulum STL/Roue_Dentée.STL
28.8 x 28.8 x 17.2

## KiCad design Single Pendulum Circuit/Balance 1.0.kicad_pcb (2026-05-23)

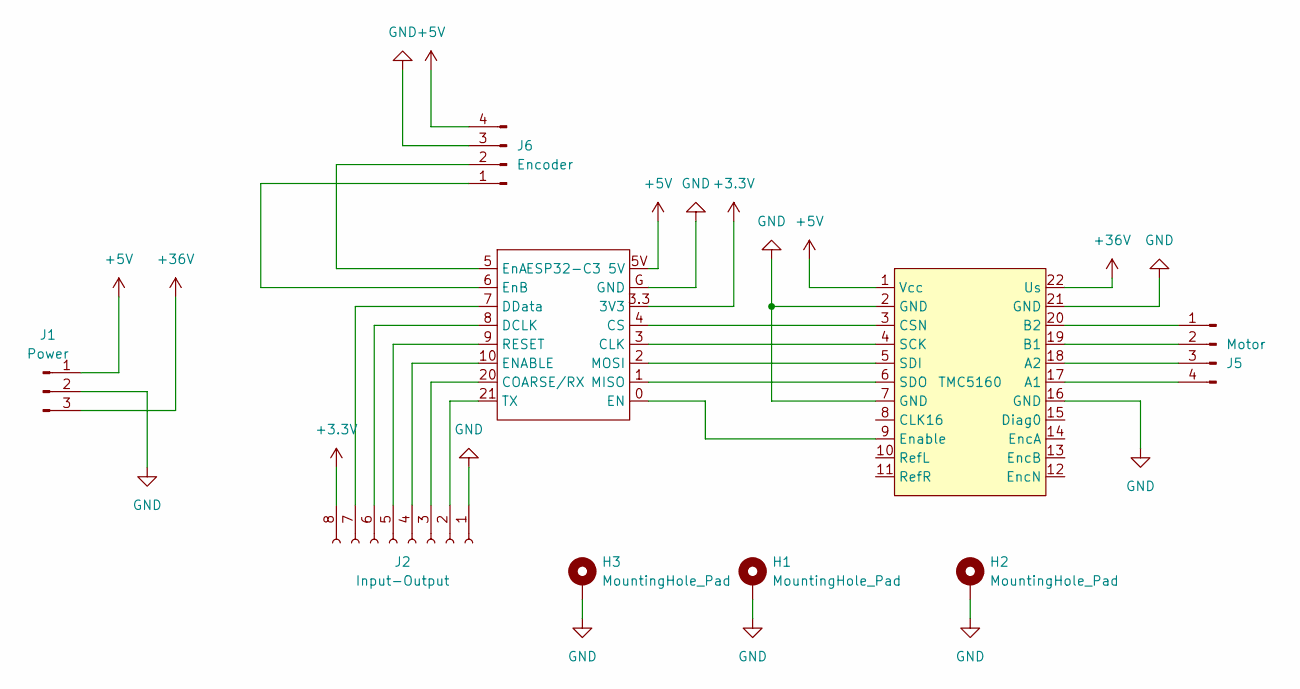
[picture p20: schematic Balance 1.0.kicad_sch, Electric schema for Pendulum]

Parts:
H1, H2, H3: MountingHole_Pad; MountingHole_3.2mm_M3_DIN965_Pad
J1: Power; JST_XH_B3B-XH-AM_1x03_P2.50mm_Vertical
J2: Input-Output; PinSocket_1x08_P2.54mm_Vertical
J5: Motor; PinHeader_1x04_P2.54mm_Vertical
J6: Encoder; PinSocket_1x04_P2.54mm_Vertical
U1: TMC5160
U2: ESP32-C3; ESP32C3

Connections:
+3.3V: J2.8, U2.3.3 (3V3)
+5V: J1.1, J6.4, U1.1 (Vcc), U2.5V
+36V: J1.3, U1.22 (Us)
GND: H1.1, H2.1, H3.1, J1.2, J2.1, J6.3, U1.2 (GND), U1.7 (GND), U1.16 (GND), U1.21 (GND), U2.G (GND)
unnamed: J2.2, U2.21 (TX)
unnamed: J2.3, U2.20 (COARSE/RX)
unnamed: J2.4, U2.10 (ENABLE)
unnamed: J2.5, U2.9 (RESET)
unnamed: J2.6, U2.8 (DCLK)
unnamed: J2.7, U2.7 (DData)
unnamed: J5.1, U1.20 (B2)
unnamed: J5.2, U1.19 (B1)
unnamed: J5.3, U1.18 (A2)
unnamed: J5.4, U1.17 (A1)
unnamed: J6.1, U2.6 (EnB)
unnamed: J6.2, U2.5 (EnA)
unnamed: U1.3 (CSN), U2.4 (CS)
unnamed: U1.9 (Enable), U2.0 (EN)
unnamed: U1.4 (SCK), U2.3 (CLK)
unnamed: U1.5 (SDI), U2.2 (MOSI)
unnamed: U1.6 (SDO), U2.1 (MISO)

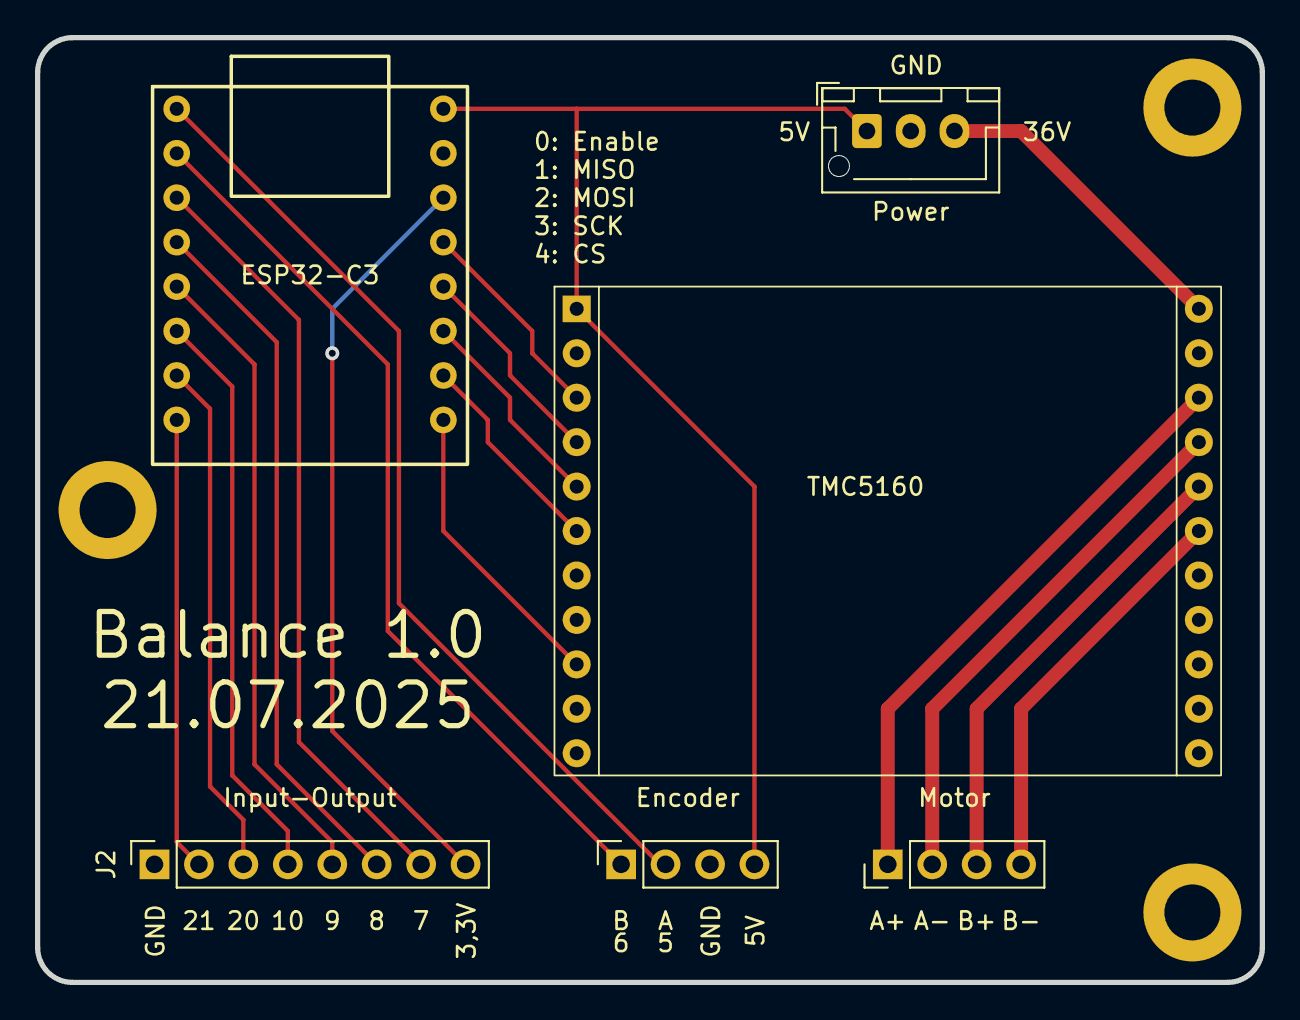
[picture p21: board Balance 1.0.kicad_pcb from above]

Board: 2 copper layers, 70.0 x 54.0 mm, 9 parts (0 on the bottom side), 21 nets.

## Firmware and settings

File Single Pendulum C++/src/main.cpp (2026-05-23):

/*
* Magdi Laoun, 13.07.2025
* Balance of a bar moved by a motor with a PID controller
* Use of TMC5160 stepper motor driver
* Use of encoder to measure the position of the bar 400 lines
* Boards: ESP32-C3 super mini, TMC5160
*/
#include <Arduino.h>
#include <Pendulum.h>

union FloatBytes {
    float value;
    uint8_t bytes[4];
  };
struct MyData {
  float pendulumAngle; //sensor 1
  float pendulumSpeed; // sensor 1
  float cartPosition; //sensor 2
  float cartSpeed; // sensor 2
  float cycleTime; //time taken for one control cycle
  float phase; //phase of the control algorithm
  
};

Pendulum pendulum; // Create Pendulum object
uint64_t lastTime = 0; //Variable to store time
uint64_t lastCycleTime = 0; //Variable to store time taken for one control cycle
uint64_t cycleTime = 0; //Variable to store time taken for one control cycle
void checkSerial();
float getFloatValue(byte *input);
void transmitData();


void setup(){
  Serial.begin(115200); //Initialize serial communication at 115200 baud rate
  
  pendulum.begin( //Initialize pendulum with parameters
    10000, //Encoder resolution in steps
    200, //Motor steps per revolution
    16, //Motor microsteps per step
    0.08f, //Pulley circumference in meters
    50, //Encoder speed count for speed calculation
    50 //Cart speed count for speed calculation
  );
}
void loop(){
  cycleTime = micros() - lastCycleTime; //Calculate time taken for one control cycle
  lastCycleTime = micros(); //Update last cycle time
  checkSerial(); //Check for serial commands
  pendulum.updateAngle(); //Update angle and angular velocity of pendulum
  pendulum.updatePosition(); //Update position and velocity of cart
  if (micros() - lastTime > 100000) { //Update computer every 0.1 seconds
    transmitData(); //Transmit data to computer
    lastTime = micros();
  }
  pendulum.action(); //Perform control action based on current phase
}
void checkSerial(){
  if (Serial.available() > 0) { //If data is available on serial port
    byte *data = (byte *) malloc(5);
    Serial.readBytes(data, 5); //Read 5 bytes from serial port
    float value = getFloatValue(data); //Extract float value from received data
    pendulum.setValue(data[0], value); //Set value in pendulum object based on received data
    free(data);
  }
}
void transmitData() {
  MyData myData; //Create data structure to hold values to transmit
  myData.pendulumAngle = pendulum.angle;
  myData.pendulumSpeed = pendulum.angularVelocity;
  myData.cartPosition = pendulum.position;
  myData.cartSpeed = pendulum.velocity;
  myData.phase = float(pendulum.phase);
  myData.cycleTime = float(cycleTime); //Convert cycle time to float for transmission in microseconds
  uint8_t len = sizeof(myData);
  byte data[len + 1];
  data[0] = 0xAA; // Start byte
  for (size_t i = 0; i < len; i++) {
    data[i + 1] = *((uint8_t*)&myData + i);
  }
  Serial.write(data, len + 1); // Transmit data over Serial
  Serial.flush();
}

float getFloatValue(byte *input) {
  
  FloatBytes fb;
  for (int i = 0; i < 4; i++) {
    fb.bytes[i] = input[i+1]; //Copy bytes from input to union
  }
  float value = fb.value; //Get float value from union
  return value;
}

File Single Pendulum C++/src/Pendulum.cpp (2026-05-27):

//#include <Arduino.h>
#include "Pendulum.h"
#define CHA GPIO_NUM_5 //Encoder channel A
#define CHB GPIO_NUM_6 //Encoder channel B
#define EN GPIO_NUM_0 //TMC5160 Enable
#define CS GPIO_NUM_4 //TMC5160 Chip select
#define MISO GPIO_NUM_1 //TMC5160 MISO
#define MOSI GPIO_NUM_2 //TMC5160 MOSI
#define SCK GPIO_NUM_3 //TMC5160 Clock
#define CW 1 //Clockwise direction
#define CCW 2 //Counter-clockwise direction
void Pendulum::begin(uint32_t encoderResolution_, uint16_t motorMicrosteps_, uint32_t motorSteps_, float pulleyCircumference_, uint16_t encoderSpeedCount_, uint16_t cartSpeedCount_) {
    encoderResolution = encoderResolution_ ;
    motorMicrosteps = motorMicrosteps_;
    motorSteps = motorSteps_;
    pulleyCircumference = pulleyCircumference_;
    motorSpd.begin(cartSpeedCount_);
    encoderSpd.begin(encoderSpeedCount_);
    encoder.begin(CHA, CHB); //Initialize encoder with pin definitions
    tmc.begin(SCK, MOSI, MISO, CS, EN); //Initialize TMC5160 with pin definitions
    updateRatios();
}
void Pendulum::updateRatios() {
  angleRatio = (2.0f * PI) / static_cast<float>(encoderResolution); // Radians per encoder step
  distanceRatio = pulleyCircumference / (static_cast<float>(motorSteps) * static_cast<float>(motorMicrosteps)); // Meters per motor step
  accelerationRatio = 0.015f / distanceRatio; //Calculate acceleration unit for the motor
  speedRatio = 1.37f / distanceRatio; //Calculate speed unit for the motor
}
void Pendulum::resetEncoder() {
  encoder.resetPosition();
}
void Pendulum::resetTMC() {
  // 0: 256, 1: 128, 2: 64, 3: 32, 4: 16, 5: 8, 6: 4, 7: 2, 8: 1
  switch (motorMicrosteps) {
    case 256: tmc.init(0.05f, 0.4f, 0); break;
    case 128: tmc.init(0.05f, 0.4f, 1); break;
    case 64: tmc.init(0.05f, 0.4f, 2); break;
    case 32: tmc.init(0.05f, 0.4f, 3); break;
    case 16: tmc.init(0.05f, 0.4f, 4); break;
    case 8: tmc.init(0.05f, 0.4f, 5); break;
    case 4: tmc.init(0.05f, 0.4f, 6); break;
    case 2: tmc.init(0.05f, 0.4f, 7); break;
    case 1: tmc.init(0.05f, 0.4f, 8); break;
    default: tmc.init(0.05f, 0.4f, 4); break; //Default to microsteps = 16
  }
}
void Pendulum::updateAngle() {
  angle = float(encoder.getPosition()) * angleRatio;
  angularVelocity = encoderSpd.update(angle);
}
void Pendulum::updatePosition() {
  long currentPosition = tmc.getPosition();
  position = float(currentPosition) * distanceRatio;
  velocity = motorSpd.update(position);
}
void Pendulum::setValue(uint8_t address, float value) {
  switch (address) {
    case 0x00: phase = (static_cast<Phase>(value)); break; //Set phase based on received value
    case 0x01: resetTMC(); break; //Reset TMC5160
    case 0x02: resetEncoder(); break; //Reset encoder position to zero
    case 0x03: setCurrent(value); break; //Set motor current
    case 0x05: xMax = value; break; //Maximum position in meters
    case 0x06: vMax = value; break; //Maximum speed in meters per second
    case 0x07: aMax = value; break; //Maximum acceleration in meters per second squared
    case 0x11: sw[0] = value; break; //position 1 for swing up controller
    case 0x12: sw[1] = value; break; //acceleration 1 for swing up controller
    case 0x13: sw[2] = value; break; //position 2 for swing up controller
    case 0x14: sw[3] = value; break; //acceleration 2 for swing up controller
    case 0x15: sw[4] = value; break; //position 3 for swing up controller
    case 0x16: sw[5] = value; break; //acceleration 3 for swing up controller
    case 0x17: sw[6] = value; break; //threshold for transition from swing up to balance up
    /*
    case 0x10: potEnergy = value; break; //initial potential energy of the pendulum
    case 0x11: kickMagnitude = value; break; //magnitude of initial kick for swing up
    case 0x12: kickAcceleration = value; break; //pulsation of kick for swing up
    case 0x13: ea = value; break; //coefficient energy angle
    case 0x14: ex = value; break; //coefficient energy position
    case 0x15: exd = value; break; //coefficient energy velocity
    case 0x16: threshold = value; break; //threshold from kick to swing up
    */
    
    case 0x20: kpa = value; break; //coefficient proportional gain for encoder
    case 0x21: kda = value; break; //coefficient derivative gain for encoder
    case 0x22: kpm = value; break; //coefficient proportional gain for motor
    case 0x23: kdm = value; break; //coefficient coefficient derivative gain for motor
    case 0x30: m = value*1.2; break; //mass of the pendulum
    case 0x31: l = value; break; //length of the pendulum
    case 0x32: loopingPulse = value; break; //magnitude of position pulse for looping
    case 0x33: balanceDownPulse = value; break; //magnitude of position pulse for balance down
    case 0x34: balanceDownThreshold = value; break; //threshold for angle in radians to transition from balance up to down
    case 0x35: origin = value; break; //origin position for the pendulum
  }
}
void Pendulum::action() {
  if (phase != lastPhase) {
    phaseCounter = 0; //Reset phase counter on phase change
    lastPhase = phase;
    lastPhaseChangeTime = millis();
    lastPosition = position; //Reset last position
  }
  switch (phase) {
    case STANDBY: standby(); break;
    case KICK: kick(); break;
    case SWINGUP: swingUp(); break;
    case BALANCEUP: balanceUp(); break;
    case BALANCEDOWN: balanceDown(); break;
    case LOOPINGCW: looping(CW); break;
    case LOOPINGCCW: looping(CCW); break;
  }
}
void Pendulum::standby() {
  tmc.setRampMode(0); //Set to position mode
  tmc.setAcceleration(aMax * accelerationRatio); //Set acceleration to maximum
  tmc.setSpeed(vMax * speedRatio); //Set speed to maximum
  tmc.targetPosition(0); //Set target position to zero
}

void Pendulum::kick() { //Apply first oscillating acceleration to swing up the pendulum
  if (millis() - lastPhaseChangeTime > 50 && abs(position - (lastPosition + kickMagnitude)) < 0.005f) {phase = SWINGUP; return;}
  //if (millis() - lastPhaseChangeTime > 100 && sin(angle)<0.0f) {phase = SWINGUP; return;}
  if (cos(angle) < cos(threshold)) { phase = BALANCEUP; return;}
  tmc.setRampMode(0); //Set to position mode
  tmc.setAcceleration(kickAcceleration * accelerationRatio); //Set acceleration for the kick
  tmc.setSpeed(vMax * speedRatio); //Set speed to maximum
  tmc.targetPosition((lastPosition + kickMagnitude)/distanceRatio); //Set target position for the kick
}

/*
void Pendulum::swingUp() {
  if (cos(angle) < -cos(threshold)) { phase = BALANCEUP; return;} //Transition to balance phase when angle exceeds threshold
  float e = getEnergyBalance();
  float signAngle = cos(angle) > 0.0f ? 1.0f : -1.0f; //Sign of the angle for energy shaping
  float signVelocity = angularVelocity < 0.0f ? 1.0f : -1.0f; //Sign of the velocity for energy shaping
  float a = ea * e * signAngle*signVelocity;// * signVelocity - ex * position - exd * velocity;
  setAcceleration(a);
}
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

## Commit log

2026-05-23 adding stl files
    [Embout_Axe.STL, Fixation_Courroie.STL, Flasque_Roue.STL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]
2026-05-23 update bill of material
2026-05-23 Update of files
    [Balance 1.0.kicad_pcb, Balance 1.0.kicad_sch, Embout_Axe.STL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]
